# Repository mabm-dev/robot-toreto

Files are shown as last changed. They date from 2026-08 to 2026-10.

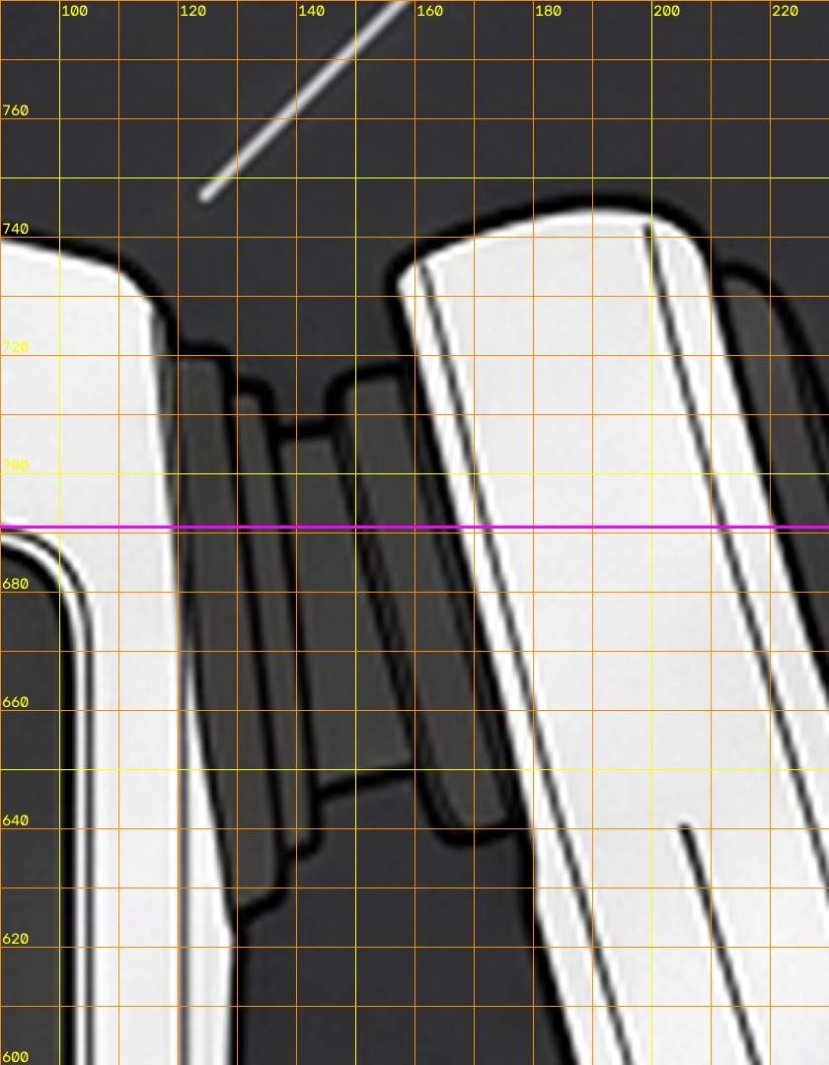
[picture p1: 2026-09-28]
work/Toreto_Prueba_Holguras_01_44/medicion_brazo/hombro_frontal.jpg

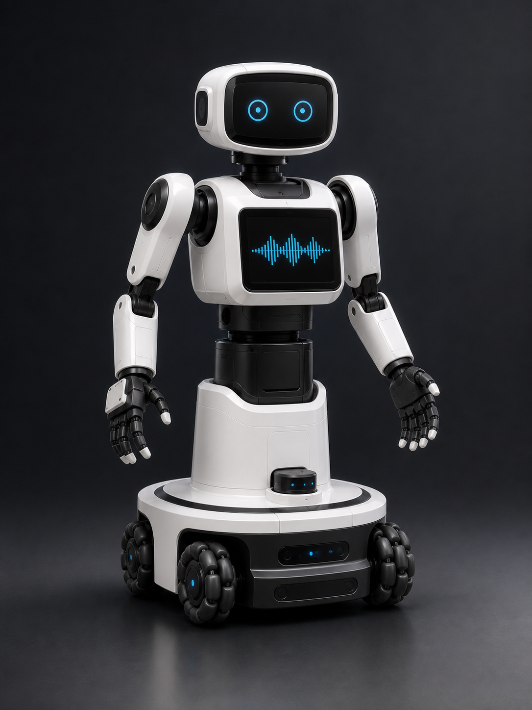
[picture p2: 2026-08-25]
cad-toreto/toreto_fusion_95cm/reference/concepto_fusion_95cm.png

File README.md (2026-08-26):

# Robot Toreto

Robot asistente de 95 cm impreso en 3D: base holonómica de 4 ruedas mecanum
con LIDAR, brazo de 6 grados de libertad por lado, cabeza de 2 grados de
libertad con cámara RGB-D, torso con pantalla táctil. Peso objetivo ~15 kg.

## Estado del proyecto

El proyecto avanza en tres fases fijas, en este orden — ver el porqué en
[`docs/DECISIONES.md`](docs/DECISIONES.md):

| Fase | Qué decide | Estado |
| --- | --- | --- |
| 1. Diseño | Forma, proporciones y módulos | 🟡 en curso — forma aprobada, proporciones finales pendientes |
| 2. Componentes | Batería, servos, motores, LIDAR, cámara, procesador | ⬜ no empezada — bloquea el resto |
| 3. CAD y materiales | Medidas definitivas y material pieza a pieza (Fusion) | 🟡 exterior avanzando — solo carcasas, sin mecánica ni cotas fijas (adelanto permitido, ver `DECISIONES.md`) |

Seguimiento del avance, en este repo:

- [`docs/ROADMAP.md`](docs/ROADMAP.md) — versiones y checklist de cada una
- [`docs/DECISIONES.md`](docs/DECISIONES.md) — por qué se tomó cada decisión
- [`docs/CINEMATICA.md`](docs/CINEMATICA.md) — árbol de links/joints previsto (planificación, no URDF final)

Documentos vivos (consulta desde cualquier dispositivo, se actualizan sobre la
misma URL):

- [Índice del proyecto](https://claude.ai/code/artifact/3c1e9e5f-cfa8-4d47-8dd7-55fb1f6f150b)
- [Lámina de diseño](https://claude.ai/code/artifact/774ba526-7714-4aee-aeff-1aad35ca3a55)
- [Stack de herramientas](https://claude.ai/code/artifact/6abfaa55-f3db-4c18-a0bd-476af38d9d59)

## Estructura del repositorio

```
cad-toreto/
├── visor-3d/                    # visor 3D interactivo (Three.js) — con este
│                                 # se aprobó la forma en v0.1
├── toreto_fusion_95cm/          # integración Autodesk Fusion 360 (fase 3, exterior)
│   ├── fusion_scripts/          #   10 add-ins de Fusion vigentes
│   ├── reference/lienzos_95cm/  #   4 vistas calibradas a 950mm + herramientas
│   │                             #   de medición (tools/measure_z_boundaries.py)
│   └── src/                     #   fuente paramétrica de la referencia volumétrica
├── toreto_exterior_95cm/        # piezas exteriores en OpenSCAD (fase 3, exterior)
│   ├── src/                     #   5 módulos .scad (base/tronco/pecho-hombros/
│   │                             #   cabeza-cuello/brazos)
│   ├── exports/                 #   STL por pieza
│   └── docs/                    #   una nota por módulo
├── toreto_v2.scad, toreto_reference_v1.scad, toreto_concept_v0.scad
│                                 # maquetas OpenSCAD anteriores (fase 1) — superadas
│                                 # por el trabajo de 95cm de arriba, se conservan
│                                 # como historial
└── exports/, exports_v1/, exports_v2/   # STL y renders de esas maquetas anteriores

docs/
├── ROADMAP.md               # versiones y checklist de cada una
├── DECISIONES.md            # por qué se tomó cada decisión importante
└── CINEMATICA.md            # árbol de links/joints previsto (planificación)
```

`toreto_fusion_95cm` y `toreto_exterior_95cm` describen el **mismo** exterior
de 95cm desde dos herramientas distintas (Fusion 360 y OpenSCAD) — hoy no
reparten los 950mm verticales de la misma forma entre sí; ver
`docs/DECISIONES.md` para el porqué no se ha fijado todavía una tabla única.

Hay también un cuaderno de aprendizaje (`docs/CUADERNO.md` en local) que es
deliberadamente privado y no está en este repositorio.

## Piezas y materiales

El trabajo exterior vigente (solo carcasas, sin mecánica) vive en
[`cad-toreto/toreto_fusion_95cm/`](cad-toreto/toreto_fusion_95cm/README.md)
(Fusion 360) y [`cad-toreto/toreto_exterior_95cm/`](cad-toreto/toreto_exterior_95cm/)
(OpenSCAD) — ver sus propios README. Ninguna pieza lleva todavía mecanismo
interno funcional (servos, reductoras, rodamientos reales): eso llega en la
fase 3 con los componentes ya elegidos, y las particiones verticales entre
módulos siguen sin fijarse por el mismo motivo (ver `docs/DECISIONES.md`).

`toreto_v2.scad` (y `lista_piezas_v2.md`, `guia_impresion_p1s.md`) es la
maqueta visual anterior — validó forma, proporción y que cada pieza entra en
el volumen de impresión de la Bambu Lab P1S (256 × 256 × 256 mm), pero está
superada por el trabajo de 95cm de arriba. Se conserva como historial, no
como referencia vigente.

Impresión: más perímetros antes que más relleno — 4-5 paredes con giroide al
25-30 %. Detalle en [`cad-toreto/guia_impresion_p1s.md`](cad-toreto/guia_impresion_p1s.md)
(de la maqueta anterior; sigue aplicando como criterio general de slicing).

## Herramientas

Fusion 360 (CAD final, fase 3), Bambu Studio (slicing), OpenSCAD (maquetas de
fase 1), KiCad / AutoCAD Electrical (electrónica), ROS 2 + Gazebo (control y
simulación, fase 3), NotebookLM (documentación).

## Licencia

Sin licencia definida todavía — todos los derechos reservados por defecto.

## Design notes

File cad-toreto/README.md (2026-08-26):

# cad-toreto — índice

Todo el CAD de Robot Toreto vive aquí, no en la raíz del repo (ver
`docs/DECISIONES.md` en la raíz para el porqué de cada decisión). Esta
carpeta acumula varias generaciones de trabajo — de más reciente/vigente a
más antigua/histórica:

## Vigente (fase 3, exterior — sin mecánica ni cotas fijas)

- **[`toreto_fusion_95cm/`](toreto_fusion_95cm/README.md)** — integración
  Autodesk Fusion 360: 10 add-ins, las 4 vistas de referencia calibradas a
  950mm (`reference/lienzos_95cm/`) y las herramientas que las generan y
  miden (`tools/`).
- **[`toreto_exterior_95cm/`](toreto_exterior_95cm/README.md)** — las mismas
  piezas exteriores en OpenSCAD: 5 módulos fuente, STL exportados y un
  render/doc por módulo.

Ambas carpetas describen el **mismo** exterior de 95cm desde herramientas
distintas y hoy no reparten los 950mm verticales de la misma forma entre sí
— la tabla única de cotas está deliberadamente sin fijar porque depende de
dónde queden batería y mecanismos internos (fase 2, todavía sin cerrar).

## Vigente (fase 1 — visor de forma)

- **[`visor-3d/`](visor-3d/README.md)** — visor 3D interactivo en Three.js;
  con él se aprobó la forma del robot (milestone v0.1 del roadmap).

## Histórico (maquetas anteriores, superadas)

- `toreto_v2.scad` (+ `lista_piezas_v2.md`, `README_V2.md`,
  `STL_EXPORTADOS_V2.md`, `exports_v2/`) — última maqueta OpenSCAD de fase 1
  antes de migrar a Fusion. Validó forma, proporción y que cada pieza cabe
  en el volumen de la Bambu P1S (256×256×256mm); no lleva mecanismo interno.
- `toreto_reference_v1.scad` (+ `README_V1_REFERENCIA.md`,
  `STL_EXPORTADOS_V1.md`, `exports_v1/`) y `toreto_concept_v0.scad`
  (+ `lista_piezas_concepto.md`) — generaciones anteriores a v2.
- `guia_impresion_p1s.md` — perfiles de slicing; el criterio general (más
  perímetros que relleno) sigue aplicando aunque las piezas cambien.
- `MIGRACION_95CM.md` — nota de la consolidación del 25 ago 2026 que separó
  lo que sí pasaba a 95cm de lo que se descartaba (rama de 65cm con servos
  ST-3215 ya elegidos — ver `toreto-gpt-descartado` en la memoria del
  proyecto, no forma parte de este repo).

No confundir con la carpeta hermana `cad-toreto-gpt/` (fuera de este repo,
en `.gitignore`) — es una rama paralela de 65cm descartada, no el proyecto
activo.

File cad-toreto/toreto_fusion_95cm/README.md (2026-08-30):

# Robot Toreto Fusion 95 cm

Integración de Autodesk Fusion 360 y referencias dimensionales del diseño
exterior vigente. Esta carpeta no contiene la antigua rama funcional de 65 cm.

## Alcance

- Altura exterior exacta: **950 mm**.
- Base compacta: **Ø400 × 225 mm**.
- Cuatro ruedas mecanum mostradas únicamente como volumen visual.
- Tronco, cintura, pecho, cuello y cabeza en módulos desmontables.
- Pantalla frontal horizontal.
- Brazos de **170 mm + 150 mm**.
- Mano antropomórfica: cuatro dedos de tres falanges y pulgar de dos falanges.
- Solo carcasas y piezas exteriores.

No incluye motores, esqueleto, rodamientos, ejes, cableado, electrónica ni
anclajes definitivos. Los alojamientos funcionales se diseñarán después de
seleccionar y medir los componentes reales.

## Distribución vertical de referencia

La tabla actualmente adoptada es la medida sobre la lámina maestra calibrada.
Las cotas internas y tolerancias siguen pendientes de los componentes reales.

| Módulo | Altura | Cota superior |
|---|---:|---:|
| Base | 200 mm | 200 mm |
| Tronco blanco | 190 mm | 390 mm |
| Cintura negra | 150 mm | 540 mm |
| Pecho | 190 mm | 730 mm |
| Cuello | 60 mm | 790 mm |
| Cabeza | 160 mm | 950 mm |

## Archivos conservados

- `fusion_scripts/`: versiones vigentes de los complementos de Fusion 360.
- `reference/lienzos_95cm/`: frontal, posterior y dos laterales calibrados
  entre `Z=0` y `Z=950 mm`.
- `reference/toreto_fusion_95cm_assembly.stl`: referencia volumétrica, no pieza
  fabricable.
- `reference/`: imágenes conceptuales aprobadas.
- `src/`: fuente paramétrica usada para regenerar la referencia volumétrica.
- `tools/prepare_fusion_canvases.py`: preparación reproducible de los lienzos.

Las piezas exteriores exportables vigentes están en la carpeta hermana
`toreto_exterior_95cm`; se retiraron de aquí los STL preliminares duplicados.

## Estado

Es una maqueta CAD exterior y paramétrica para cerrar apariencia, partición y
volúmenes. Los complementos construyen geometría de revisión, no mecánica
definitiva. Antes de imprimir el conjunto completo hay que:

1. confirmar motores, ruedas, servos, sensores y batería;
2. introducir sus envolventes reales en Fusion 360;
3. definir tornillería, insertos, tolerancias y nervios;
4. comprobar alcance y par de brazos;
5. laminar prototipos parciales en Bambu Studio u OrcaSlicer.

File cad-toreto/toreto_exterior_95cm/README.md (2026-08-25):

# Robot Toreto — piezas exteriores de 95 cm

Diseño por módulos basado directamente en la referencia visual aportada. El
trabajo se organiza en este orden:

1. Base.
2. Tronco.
3. Hombros y pecho.
4. Cabeza y cuello.
5. Brazos y manos.

El alcance incluye únicamente carcasas, paneles y acabados visibles. No incluye
ruedas, motores, servos, ejes, rodamientos, chasis, esqueleto ni anclajes.

## Módulos conservados

- `src/`: fuentes paramétricas OpenSCAD y exportadores de los cinco módulos.
- `docs/`: cotas, despiece y límites de cada módulo.
- `exports/`: STL exteriores separados por módulo.
- `renders/`: vistas de comprobación estética.

Los STL de esta carpeta son piezas exteriores de referencia. Antes de fabricar
hay que revisar espesores, tolerancias, uniones y compatibilidad con el hardware
real que se seleccione.

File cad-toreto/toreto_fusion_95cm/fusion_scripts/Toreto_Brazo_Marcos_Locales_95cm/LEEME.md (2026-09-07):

# Brazo Toreto — prueba de marcos locales 1.0.35

La 1.0.35 conserva exactamente la implantacion y el giro hacia dentro del
pulgar de la 1.0.34. Invierte el sentido de flexion de los cuatro dedos
principales para que cierren desde la cara opuesta de la palma.

Las dieciseis juntas principales usan ahora los intervalos -60..0, -60..0,
-50..0 y -40..0 grados. Los topes fisicos se trasladan al mismo lado angular,
incluida la compensacion por contacto de los nervios. Las relaciones mantienen
las magnitudes progresivas 60/60/50/40. El pulgar conserva sus intervalos
0..30, 0..40, 0..35 y 0..20 grados, sus ejes, su posicion y su geometria.

Para validar en Fusion, anima las relaciones de `JUNTA_DEDO_1_1` y despues
`JUNTA_PULGAR_1`: deben cerrar hacia caras opuestas y encontrarse sobre la
palma sin cambiar la posicion abierta.

La 1.0.34 conserva la forma de giro validada visualmente en la 1.0.33, pero
refleja toda la implantacion del pulgar al lado opuesto del cierre de los dedos
principales. El anclaje, el cardan, las tres falanges y sus cuatro ejes se
transforman como un único mecanismo respecto al plano medio Y=48,4595 mm.

El pulgar abierto queda en la cara Y positiva, con la raiz en Y=68,0641 mm y
el anclaje en la misma cara exterior, Y=58,4595 mm. Al cerrar, las falanges
proximales permanecen fuera de la cubierta y la yema gira hacia dentro hasta
Y=47,32 mm. La horquilla abierta de 10 mm evita que el cardan nazca dentro de
la base maciza.

Se conservan los recorridos 30/40/35/20, la separacion de 76 grados entre los
ejes de base, las 20 juntas, las 15 relaciones y todas las fijaciones.

La 1.0.33 corrige el signo de profundidad de la 1.0.32. Los dedos principales
cierran hacia la cara Y positiva, por lo que el pulgar debe partir en la cara
opuesta. La cadena se desplaza 16 mm hacia Y negativa y los dos ejes del cardan
se recalculan con una separacion aproximada de 76 grados.

La abertura del soporte aumenta de 7,2 a 10 mm y atraviesa el extremo de la
base reforzada, formando una horquilla real alrededor del cardan. Durante el
cierre calculado, los tres puntos proximales se mantienen fuera de la palma en
Y=28,9, 25,7 y 28,2 mm. Despues la cadena cruza bajo el borde: la siguiente
articulacion alcanza Y=38,9 mm y la yema Y=49,6 mm para oponerse a los dedos.

Se conservan los recorridos 30/40/35/20, las 20 juntas, las 15 relaciones y
las fijaciones completas del brazo, de la mano y de la palma.

La 1.0.32 corrige la penetracion fisica visible en las vistas lateral y oblicua
de la 1.0.31. La base reforzada terminaba en un volumen macizo alrededor del
primer pivote, por lo que el cardan y la primera falange atravesaban la propia
palma al cerrar.

Ahora la base incorpora una cuna abierta de 7,2 mm de radio entre los dos ejes
del cardan. La cadena completa del pulgar se adelanta 14 mm hacia la cara
palmar y sus ejes cruzados se recalculan con una separacion aproximada de 88
grados. En la postura cerrada calculada, los tres puntos proximales quedan a
58,9, 61,9 y 63,9 mm de profundidad, delante de la cubierta, mientras la yema
regresa a 54,4 mm para oponerse a los dedos.

Se conservan los recorridos 30/40/35/20, las 20 juntas, las 15 relaciones y
las fijaciones completas del brazo, de la mano y de la palma.

La 1.0.31 afina la trayectoria observada en las dos animaciones de la 1.0.30.
Reduce el barrido lateral de la primera junta del pulgar de 40 a 30 grados,
aumenta la oposicion de la segunda de 30 a 40 grados, mantiene 35 grados en la
tercera y reduce la terminal de 25 a 20 grados. El objetivo es eliminar la
forma de Z, redondear el cierre y orientar mejor la yema hacia los dedos.

Se conserva sin cambios el cardan de ejes cruzados, los 21 componentes, las 20
juntas, las 15 relaciones de movimiento, los cuatro dedos principales y todas
las fijaciones del brazo y de la mano.

La 1.0.30 incorpora un pequeño cardan entre la palma y la primera falange del
pulgar. Sus dos ejes de base se cruzan aproximadamente 78 grados: el primero
produce un barrido lateral de 40 grados y el segundo añade 30 grados de
oposicion hacia los tres dedos derechos. Las dos bisagras distales, paralelas
al eje de oposicion, aportan 35 y 25 grados para completar el cierre natural.

La cadena del pulgar pasa a tener cuatro juntas y tres relaciones de cierre.
La mano contiene 21 componentes, 20 juntas revolutas y 15 relaciones de
movimiento. Se mantienen los limites 60/60/50/40 de los cuatro dedos
principales y la fijacion del brazo, del conjunto de mano y de la palma.

La 1.0.29 sustituye el barrido plano del pulgar de la 1.0.28 por una flexion
oblicua. El eje se calcula a partir del rayo abierto del pulgar y del centro de
las raices de los tres dedos situados a su derecha. Las tres bisagras quedan
paralelas en ese plano y usan 50/25/15 grados; esta combinacion lleva la punta
hacia dicho centro con una curva continua y evita plegarla sobre si misma.

Tambien fija a la raiz el componente superior completo. La mano y la palma ya
estaban fijadas internamente, pero Fusion podia escoger el brazo como lado
movil al animar relaciones desde `JUNTA_DEDO_n_2`, `_3` o `_4`. Esta fijacion
mantiene inmovil todo el brazo independientemente de la junta conducida.

La 1.0.28 corrige la trayectoria del pulgar observada en la animacion de la
1.0.27. Su primera bisagra deja de usar el mismo eje transversal que las otras
dos: ahora gira alrededor de la normal negativa de la palma. En la postura
frontal aprobada, este eje desplaza el pulgar hacia los tres dedos situados a
su derecha y crea el movimiento de oposicion.

Las juntas segunda y tercera mantienen sus ejes transversales para curvar la
punta durante la oposicion. Se conservan los recorridos 60/55/45 grados, las
dos relaciones de movimiento del pulgar y todos los valores de los cuatro
dedos principales.

La 1.0.27 aumenta el cierre de los dedos principales con un reparto progresivo
de 60/60/50/40 grados. Las dos primeras juntas acercan toda la cadena a la
palma; las dos ultimas orientan la punta sin plegarla en exceso sobre si misma.

El pulgar queda adaptado a 60/55/45 grados y recibe dos relaciones de
movimiento. En total se crean catorce relaciones: doce para los cuatro dedos
principales y dos para el pulgar. Los valores de cada relacion reproducen la
proporcion de los limites y los topes fisicos correspondientes.

La 1.0.26 limita a 45 grados cada una de las cuatro juntas de los dedos
principales. Los topes fisicos se regeneran con el mismo recorrido. El cierre
acumulado puede alcanzar 180 grados, pero se reparte entre las cuatro falanges
en vez de concentrar 90 grados o mas en cada nudillo.

Tambien crea doce relaciones de movimiento: la primera junta de cada dedo
controla las otras tres con relacion 1:1. Para comprobar el cierre conjunto en
Fusion debe usarse `Animar relaciones de unión` sobre `JUNTA_DEDO_n_1`.
`Editar límites de movimiento` sigue previsualizando una junta aislada.

La 1.0.25 corrige el sentido estructural observado al animar
`JUNTA_DEDO_1_1` en la 1.0.24. Fusion mueve el primer componente indicado al
crear una junta respecto al segundo. La versión anterior entregaba primero la
palma o la falange proximal, de modo que la animación desplazaba la mano
completa alrededor del dedo seleccionado.

Ahora cada junta entrega primero la falange distal y después la palma o
falange proximal. También fija temporalmente `06_MANO_ARTICULABLE` a su
componente padre, además de mantener fijada la palma dentro del subconjunto.
Al animar una junta debe permanecer inmóvil el brazo y girar únicamente la
falange seleccionada. `Animar relaciones de unión` permitirá comprobar después
el movimiento de toda la cadena distal.

La 1.0.24 utiliza la jerarquía validada en la 1.0.23 para crear 19 juntas
revolutas reales: cuatro por cada dedo principal y tres para el pulgar. La
palma queda fijada al componente `06_MANO_ARTICULABLE`; cada falange mantiene
un único grado de libertad alrededor del pasador transversal correspondiente.

El eje de cada junta se obtiene directamente de un borde circular del pasador.
El script verifica que su radio sea 2 mm y que su normal coincida con el eje
transversal calculado. Si la orientación del borde está invertida, invierte
también el intervalo angular para conservar el cierre hacia la palma.

Las juntas principales usan límites 0–90°, 0–100°, 0–85° y 0–65°. Las juntas
del pulgar usan 0–70°, 0–90° y 0–75°. Fusion puede conducir cada junta dentro
de esos intervalos sin recolocar la postura abierta durante su creación.

La 1.0.23 conserva exactamente la geometría y los topes validados en la
1.0.22, pero reorganiza la mano como un conjunto mecánico. Bajo el componente
`06_MANO_ARTICULABLE` crea 20 componentes hijos: la palma, las 16 falanges de
los cuatro dedos principales y las tres falanges del pulgar.

En cada articulación, los dos casquillos exteriores y el pasador desmontable
pertenecen al componente proximal. El casquillo central pertenece al componente
distal junto con su falange. Esta distribución hace que cada pareja comparta
el mismo eje físico y deja preparada la jerarquía necesaria para crear juntas
revolutas con límites angulares en la siguiente etapa.

Los sólidos conservan sus coordenadas globales y las ocurrencias nuevas usan
transformación identidad. Por ello la postura, la alineación con la muñeca y
la silueta no deben cambiar respecto a la 1.0.22. El recuento sigue siendo de
96 cuerpos para la mano y 101 para el conjunto completo.

La 1.0.22 conserva la mano, la palma y los 96 cuerpos validados en la 1.0.21.
Cada nudillo incorpora ahora un tope móvil unido al casquillo central y dos
topes fijos unidos a los casquillos exteriores. Son nervios cilíndricos de
1,25 mm de radio que se integran mediante unión booleana, de modo que no crean
piezas sueltas ni interfieren con el taladro o con la extracción del pasador.

Los recorridos nominales de los cuatro nudillos de cada dedo son 90°, 100°,
85° y 65° desde la palma hacia la punta. Los tres recorridos del pulgar son
70°, 90° y 75°. La posición angular incluye el radio de contacto de ambos
topes para que el contacto ocurra al alcanzar el límite y no antes.

Esta versión comprueba en Fusion la creación de las uniones booleanas y que
los topes permanezcan fuera del taladro. Los canales de accionamiento y la
conversión de falanges a componentes móviles quedan para la etapa siguiente.

La 1.0.21 conserva la geometría exterior aprobada en la 1.0.20 y sustituye los
19 cilindros visuales de los dedos por articulaciones mecánicas. Cada nudillo
contiene dos casquillos exteriores, un casquillo central y un pasador coaxial
independiente.

El pasador tiene 4 mm de diámetro y sobresale 1 mm por cada lado. Los casquillos
usan un taladro de 4,70 mm, equivalente a 0,35 mm de holgura radial, y dejan
0,40 mm de separación axial a cada lado del casquillo central. Los cuatro
cuerpos permiten comprobar visualmente el montaje y mantienen accesible el
pasador para desmontaje.

Esta etapa valida primero los casquillos, taladros y pasadores en Fusion. Los
límites nominales previstos son 90° / 100° / 85° / 65°. Los topes físicos y los
canales de accionamiento se incorporarán después de confirmar que los 19
conjuntos se generan sin errores y mantienen la silueta aprobada.

La 1.0.20 elimina la forma de campana visible en la vista inferior. La
profundidad de la palma negra baja de 44 a 20 mm en el nacimiento de los dedos,
frente a falanges de 14–15 mm. Aumenta gradualmente a 21, 22, 24 y 26 mm al
acercarse al conector de muñeca, cuyo diámetro de 26 mm queda completamente
recibido.

El desplazamiento del centro en profundidad se reduce de 8 a 2,5 mm para que
la palma se lea como una placa humanoide. Los cuatro dedos se trasladan 5,5 mm
con la nueva superficie de nudillos; sus longitudes, alineación, ejes, arco
cubital, cunas separadas y terminales abombadas permanecen intactos.

La 1.0.19 conserva exactamente la alineación de palma, nudillos y dedos de la
1.0.18. Sustituye las esferas terminales por falanges blancas de cuatro
secciones: mantienen su anchura durante el 68 % de la longitud y se reducen
progresivamente hasta un extremo abombado. La terminal recibe ahora el 27 % de
la longitud total de cada dedo.

Las cunas de los nudillos reducen su radio a 7 mm y penetran 6 mm en la palma.
Así permanecen separadas por material visible en vez de formar un borde recto
continuo. El arco transversal se reparte en 1,5 / 0 / 2,5 / 5 mm desde el índice
hasta el meñique, aumentando la capacidad de ahuecar la palma hacia el lado
cubital. El pulgar utiliza la misma terminal abombada sin esfera.

La 1.0.18 usa el conector negro de muñeca como eje maestro de toda la mano.
La palma rota 13,40 grados respecto a la postura heredada, sus centros locales
se alinean sobre una recta y la fila de nudillos se construye perpendicular a
ese eje. Los cuatro dedos salen paralelos al conector, sin abanico ni torsión.

La palma mide ahora 60 mm de longitud y conserva 76 × 44 mm en los nudillos.
Cuatro cunas redondeadas se integran en su borde para recibir las articulaciones
proximales. Los dos dedos centrales avanzan 2 mm en profundidad para crear un
arco palmar suave. Las falanges terminales blancas son más largas y anchas.

El pulgar rota junto con la palma, aumenta hasta 18 × 16 mm en su base y su
tercera falange se convierte en una terminal blanca alargada y redondeada.

La 1.0.17 gira los ejes de los nudillos 90 grados respecto a la prueba anterior.
Cada eje se calcula como el transversal del rayo local de su dedo: atraviesa el
ancho de la falange y permite que el movimiento ocurra en profundidad, hacia la
palma. En frontal debe leerse como una banda y en lateral como un círculo.

La palma crece moderadamente hasta 76 × 44 mm en el borde de nudillos. Las
raíces se separan 16,5 mm, las carcasas aumentan aproximadamente un 10 %, las
longitudes crecen un 3 % y la falange blanca terminal recibe más longitud y
volumen. El pulgar conserva la oposición neutra y usa su propio eje transversal
oblicuo, calculado desde su dirección.

La 1.0.16 convierte el esqueleto cinemático de la 1.0.15 en una mano modular
más próxima a las referencias. Las falanges principales aumentan hasta
14 × 13 mm en la base y 13 × 12,5 mm en la punta. Entre ellas aparecen nudillos
cilíndricos transversales independientes, incluido el nudillo de la palma.

Los cuatro dedos conservan sus longitudes diferentes, separan sus raíces a
15 mm y forman un abanico neutro total de 6 grados. La cuarta falange es blanca,
alargada y redondeada. El borde de la palma crece hasta 68 × 40 mm para rodear
las bases. El pulgar queda recto en oposición neutra y recibe tres nudillos
independientes. Las futuras posturas curvas se obtendrán girando estos cuerpos.

La 1.0.15 corrige la cinemática visual de los cuatro dedos principales usando
las nuevas referencias `manos robot.png` y `Copy_arm_design_from_image_202608242013.jpeg`.
Cada dedo nace en la posición ya aprobada y queda recto en reposo. Su eje tiene
una ligera convergencia hacia el centro de agarre, pero ninguna falange contiene
una curvatura permanente.

Cada dedo se divide ahora en cuatro cuerpos articulables: tres falanges negras
y una falange terminal blanca con punta redondeada. La longitud total de cada
dedo se conserva y se reparte en proporciones 29/27/24/20. La futura postura de
agarre se obtendrá girando las uniones transversales entre cuerpos.

La 1.0.13 colocó la rótula en el centro del perfil terminal, pero ese perfil
incluye la antigua protuberancia lateral de la horquilla. Por eso la muñeca
apareció desplazada aunque su salida siguiera la dirección del antebrazo.

La 1.0.14 conserva la altura longitudinal del extremo y toma el centro
transversal del primer perfil estable del núcleo. La corrección es de
0,08 mm en X, -23,49 mm en Y y 0,02 mm en Z. La envolvente, la rótula, el
conector y la mano completa se trasladan juntos, de modo que el esfuerzo entra
por el centro resistente del antebrazo y todas las uniones permanecen alineadas.

Las capturas de la 1.0.12 validaron la nueva mano y el pulgar reforzado. También
mostraron que la protección blanca de muñeca seguía abierta como una horquilla,
dejando demasiado vástago negro visible y concentrando el esfuerzo en la salida.

La 1.0.13 sustituye ese alojamiento por una envolvente esférica blanca R31,80 mm
unida al antebrazo. En su interior deja una cavidad para la rótula negra R13,36
mm y abre un único conducto inferior alineado con el eje del antebrazo. El
conector negro aumenta de R11 a R13 mm y nace exactamente en el centro de la
rótula. La protección queda cerrada delante, detrás y en ambos laterales; solo
queda abierta la salida necesaria hacia la palma.

Las vistas frontal y lateral derecha de la 1.0.11 confirmaron la nueva palma,
pero mostraron que el pulgar seguía comportándose como una pinza en voladizo:
su raíz estaba demasiado alejada en profundidad y dependía de un enlace fino.

La 1.0.12 adopta la arquitectura de `concepto_mano_5_dedos.png` y del módulo
`arms_exterior_95cm.scad` del repositorio. El pulgar nace de una base lateral
R12 mm integrada en la palma, permanece cerca de su plano de trabajo y utiliza
tres falanges robustas de 16 × 14, 14 × 12 y 12 × 10 mm. Los centros de sus
tramos quedan separados aproximadamente 28,6, 20,0 y 15,3 mm. Los cuatro dedos
principales, la palma 1.0.11 y todas las articulaciones del brazo se conservan.

Fusion creó correctamente la 1.0.10 y confirmó las nuevas falanges rectangulares
redondeadas. La revisión visual mostró que la palma negra era demasiado corta
y profunda, con una apertura que recordaba a una campana. La 1.0.11 conserva
la articulación de muñeca, el metacarpiano del pulgar y las cinco trayectorias,
pero rehace la silueta de la palma con cinco perfiles.

La palma mide 51 mm entre el frente de nudillos y la muñeca. Su ancho disminuye
de 60 a 38 mm y su profundidad de 36 a 26 mm. Así queda más larga, delgada y
claramente separada de la articulación circular de la muñeca.

Las capturas de la 1.0.9 validaron la unión del pulgar, la posición de la mano
y las proporciones de sus cinco trayectorias. La 1.0.10 conserva exactamente
los puntos medidos y el recorte de 0,6 mm en cada extremo de falange. Sustituye
solo los cilindros provisionales por carcasas macizas de sección rectangular
redondeada, con una reducción del 6 % hacia la punta. Cada dedo decrece de
11 × 10 a 9 × 8 mm; el pulgar decrece de 14 × 12 a 12 × 10 mm.

Esta versión sigue usando cuerpos independientes para cada falange. La prueba
comprueba el acabado exterior; los pasadores, las holguras de giro y el espesor
de pared se definirán después de aprobar la silueta.

La 1.0.8 corrigió el volumen de la palma y la posición de los cuatro dedos.
Las capturas mostraron que la primera falange del pulgar quedaba separada en
el espacio. La 1.0.9 añade un metacarpiano negro R8 mm desde el centro interior
del extremo proximal de la palma hasta la raíz medida del pulgar. Se une a la
palma, solapa con la primera falange y conserva la trayectoria del pulgar.

La 1.0.7 confirmó la colocación de la mano, pero la palma quedó sobredimensionada
porque la envolvente incluía también la rama del pulgar. La 1.0.8 rastrea el
intervalo principal de la palma por separado: el ancho pasa de 53,80 a 56,74
mm y la profundidad central se reduce progresivamente de 80 a 62 mm. Los
cuatro dedos se desplazan sobre ese intervalo principal para que sus bases
queden dentro de la palma. El pulgar conserva su trayectoria independiente.

Las vistas de Fusion validaron el hombro y la muñeca de la 1.0.6. La 1.0.7
añade una primera reconstrucción completa de la mano. La palma utiliza cuatro
secciones locales estables del contorno medido; un enlace negro R11 mm la une
al eje de muñeca. Los cuatro dedos tienen tres falanges independientes y el
pulgar dos. Las trayectorias X/Z proceden de las guías frontales y la posición
Y de las guías laterales transformadas al marco propio de la mano. Las puntas
son cuerpos blancos separados.

Esta etapa valida postura y proporciones exteriores. Las falanges aún son
cilíndricas y no incluyen pasadores ni límites de giro; se mantienen separadas
para reemplazarlas por carcasas detalladas después de validar el conjunto.

Las vistas frontal y lateral validaron el codo de la 1.0.5. La 1.0.6 conserva
sin cambios esa geometría y utiliza los dos perfiles terminales que no podían
interpolarse como articulaciones independientes. El extremo del brazo define
un alojamiento lateral de hombro de 110,63 mm de diámetro y 17,86 mm de
longitud. El extremo del antebrazo define una brida de muñeca de 63,60 mm de
diámetro y 10,32 mm de longitud. Ambos reciben ejes negros separados con 0,8
mm de holgura radial.

El loft del brazo termina ahora antes del perfil de hombro y el del antebrazo
antes del perfil de muñeca. Así se elimina la extensión provisional de perfil
constante y cada cambio abrupto corresponde a una pieza real del conjunto.

La vista lateral de la 1.0.4 validó el aro y el eje. La frontal mostró que un
cilindro blanco continuo cerraba el hueco central. La 1.0.5 divide el
alojamiento en dos mejillas laterales de 8,89 mm y deja entre ellas la abertura
de 47,57 mm medida en el contorno frontal. El eje y el enlace negros quedan
visibles en el centro, mientras la vista lateral conserva el aro blanco.

La comparación de la 1.0.3 con el lateral de referencia mostró que el eje era
correcto, pero todavía faltaban dos volúmenes visibles: el alojamiento circular
blanco solidario al antebrazo y el enlace negro entre el extremo del brazo y
el pivote. La 1.0.4 los añade alrededor del mismo centro ya validado.

El alojamiento exterior usa R27,78 mm y el taladro mantiene 0,8 mm de holgura
respecto al eje. El brazo se recorta alrededor del alojamiento completo para
evitar solapes. El eje y su enlace forman un cuerpo negro independiente del
antebrazo, conservando la separación necesaria para una articulación futura.

Las capturas de la 1.0.2 confirman que el eje se ve como puente rectangular
en frontal y como círculo en lateral. La 1.0.3 corta en las dos carcasas sendos
alojamientos coaxiales con el mismo eje y 0,8 mm de holgura radial. El cortador
penetra 2,3 mm desde cada plano terminal para eliminar el contacto plano sin
debilitar el núcleo. El eje continúa siendo un cuerpo independiente.

Las capturas de Fusion de la 1.0.1 validaron los dos núcleos: superficies
continuas, silueta frontal estable y profundidad sin pliegues. La 1.0.2
prolonga el perfil estable más próximo hasta cada plano terminal medido. De
esta forma completa la longitud sin interpolar los radios extremos que
autointersectaban el loft. Los collares solapan 0,5 mm con el núcleo antes de
unirse.

El hueco entre los planos opuestos del brazo y antebrazo determina ahora un
eje transversal de codo independiente. Su centro y radio proceden de esos dos
planos, y su dirección es la normal frontal media de los enlaces. Sigue siendo
una validación volumétrica: aún no define tolerancias, rodamientos ni espesor.

Fusion rechazó el loft completo 1.0.0 por autointersección. El diagnóstico
numérico localizó el pliegue en los cambios extremos: el último salto del brazo
y el primero y los dos últimos del antebrazo cambian de centro/radio más rápido
que su separación longitudinal. La 1.0.1 selecciona automáticamente el tramo
continuo más largo con razón de cambio local máxima 1.5. Conserva las 17
secciones medidas en el JSON; únicamente aplaza los perfiles terminales para
que esta ejecución valide primero los dos volúmenes principales.

Las vistas frontal y lateral muestran posturas distintas. Sus guías confirman
que no representan el mismo eje global: brazo 161.20/120.81 mm y antebrazo
90.25/131.53 mm en frontal/lateral. Cruzarlas mediante planos horizontales Z,
como en las pruebas 1.0.2–1.0.10, mezcla regiones longitudinales distintas.

Esta prueba no reinicia los trazados. Convierte cada contorno existente a un
marco propio definido por `upper_shell_axis` o `forearm_shell_axis`. En cada
vista mide la envolvente perpendicular a ese eje y empareja ancho/profundidad
por posición longitudinal normalizada. Luego orienta el sólido con el eje
frontal, que sigue siendo la postura maestra. El lateral aporta profundidad,
sin imponer su postura global.

Se usa Y=45 mm como plano neutro compartido para colocar ambos enlaces en la
postura frontal. Es una colocación visual de prueba, no una cota mecánica. La
geometría conserva desplazamientos locales respecto a las guías, por lo que
las secciones no quedan forzadas a centros simétricos.

Los extremos se limitan a un intervalo continuo con ancho y profundidad de al
menos 10 mm. Hay 17 secciones por pieza, más densas cerca de los extremos.
Cuando un rebaje crea varios intervalos se usa la envolvente exterior; por eso
esta primera prueba local no contiene aberturas. Tampoco incluye articulaciones,
mano, espesor o mecanismo.

Ejecutar `Toreto_Brazo_Marcos_Locales_95cm`. Crea
`94_BRAZO_MARCOS_LOCALES_PRUEBA_01` sin modificar las pruebas 90–92 ni los
lienzos. Ocultar manualmente los demás brazos para comparar superficies y la
silueta frontal. No se espera superposición con el lienzo lateral mientras el
modelo esté en la postura frontal.

La sintaxis y los cálculos numéricos se comprueban localmente. La ejecución del
loft y la calidad de sus superficies requieren Fusion. El usuario guarda el
documento de Fusion.

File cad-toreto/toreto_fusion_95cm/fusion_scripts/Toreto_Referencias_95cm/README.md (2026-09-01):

# Toreto_Referencias_95cm

Secuencia de Autodesk Fusion para colocar dentro de `00_REFERENCIAS` cuatro
lienzos ortogonales del robot:

- `PATRON_01_FRONTAL_95CM` y `PATRON_02_POSTERIOR_95CM`, en el plano XZ;
- `PATRON_03_LATERAL_IZQUIERDO_95CM` y
  `PATRON_04_LATERAL_DERECHO_95CM`, en el plano YZ;
- la malla STL completa, si existe, como comprobación adicional.

Todos los lienzos comparten escala y origen: contacto con el suelo en `Z=0`
y parte superior de la cabeza en `Z=950 mm`. Solo el frontal queda visible al
terminar. En `00_REFERENCIAS > Lienzos`, apaga su bombilla y enciende la vista
que necesites para evitar superposiciones.

Desde la versión 2.1.0, las cuatro siluetas se calibran de forma independiente
contra sus límites auditados y ocupan exactamente 1900 intervalos a
`0,5 mm/píxel`; los márgenes originales de la lámina no afectan a la escala.

La versión 2.5.0 consolida las correcciones comprobadas en Fusion:

- usa una matriz distinta para XZ y YZ, manteniendo Z vertical;
- ancla cada vista por el eje central de la base, no por el centro del PNG;
- lee los anclajes de eje desde `calibracion_95cm.json`, sin constantes
  duplicadas;
- aplica el espejo horizontal necesario en la vista lateral izquierda para
  que las dos laterales compartan la misma coordenada Y;
- elimina de `00_REFERENCIAS > Lienzos` cualquier lienzo antiguo y conserva
  exclusivamente los cuatro patrones calibrados de 95 cm.

Las referencias no son piezas fabricables. El script es repetible: actualiza
los lienzos existentes sin duplicarlos y no duplica la malla existente.

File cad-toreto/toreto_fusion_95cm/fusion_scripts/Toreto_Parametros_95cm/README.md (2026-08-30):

# Toreto_Parametros_95cm

Inicializa la única tabla vertical vigente del robot según la lámina maestra:

`200 + 190 + 150 + 190 + 60 + 160 = 950 mm`

Ejecutar primero en un documento de Fusion nuevo o antes de regenerar módulos.
Después ejecutar `Toreto_Componentes_95cm`, los generadores de piezas y, al
final, `Toreto_Alinear_Montaje_95cm`.

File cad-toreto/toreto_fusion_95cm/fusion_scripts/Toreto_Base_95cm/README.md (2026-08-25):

# Toreto_Base_95cm

Crea dentro de `01_BASE` una primera base CAD nativa a escala real:

- faldón y banda sensora;
- carcasas blancas superior e inferior;
- anillos y tapa superior;
- cuatro ruedas mecanum como piezas exteriores visuales;
- sensores frontales y torreta superior.

No crea motores, ejes, rodamientos, estructura ni electrónica. La revisión
1.2 usa ruedas radiales a 45 grados, paneles frontales redondeados, faldón
negro con cubiertas laterales blancas, torreta elevada y una tapa superior
continua. Al ejecutarla sobre la revisión anterior, sustituye solo
los cuerpos `BASE95_` creados por esta secuencia y no genera duplicados.

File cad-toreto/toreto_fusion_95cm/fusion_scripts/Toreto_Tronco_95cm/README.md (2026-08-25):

# Toreto_Tronco_95cm

Genera el módulo exterior `02_TRONCO` a partir de la altura maestra de 185 mm.
Incluye carcasa blanca cónica, núcleo negro visual, panel de sensores y tapa
de acceso. No crea estructura, batería, electrónica ni anclajes mecánicos.

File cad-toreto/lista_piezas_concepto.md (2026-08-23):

# Lista de piezas - Toreto V0

## Piezas imprimibles

| Pieza | Cantidad | Material | Comentario |
| --- | ---: | --- | --- |
| Base cuadrante | 4 | PETG | Forma el anillo exterior de 400 mm |
| Placa central base | 1 | PETG-CF | Union de base, columna y electronica |
| Caja electronica | 1 | PETG | Para reguladores, hubs y controladores |
| Tapa/sensor frontal | 1 | PETG | Huecos para sensores o camara frontal |
| Cubierta rueda | 3 | PETG | Estetica/proteccion, no rueda funcional |
| Torso frontal | 1 | PETG | Hueco de pantalla tactil |
| Torso trasero | 1 | PETG | Acceso a electronica y cableado |
| Montura hombro izquierda | 1 | PETG-CF | Debe reforzarse con eje metalico |
| Montura hombro derecha | 1 | PETG-CF | Debe reforzarse con eje metalico |
| Columna cuello | 1 | PETG-CF | Paso de cables interior |
| Cabeza frontal | 1 | PETG | Hueco de pantalla/cara y camaras |
| Cabeza trasera | 1 | PETG | Cierre de cabeza |
| Orejas/laterales cabeza | 2 | PETG | Soportes laterales |
| Brazo superior | 2 | PETG-CF | Carcasa, no estructura final unica |
| Antebrazo | 2 | PETG-CF | Carcasa, no estructura final unica |
| Muneca/pinza conceptual | 2 | PETG-CF | Concepto de pinza ligera |

## Componentes no imprimibles

| Componente | Cantidad orientativa | Nota |
| --- | ---: | --- |
| Motores con encoder para base | 3 | Mejor comprar con reductora |
| Ruedas omni/mecanum | 3 | No recomiendo imprimirlas como pieza funcional |
| Driver motores | 1-3 | Segun motor elegido |
| Bateria 24 V | 1 | Li-ion/LiFePO4 con BMS |
| Reguladores DC-DC | 2-3 | 24 V a 12 V, 5 V y/o 19 V |
| Raspberry Pi 5 / Jetson / mini PC | 1 | Control local y puente con agentes |
| ESP32 / Arduino / STM32 | 1-2 | Control en tiempo real de motores/servos |
| Camara | 1-2 | Cara/cabeza o vision frontal |
| Microfonos | 1 | Preferible array USB |
| Altavoz + amplificador | 1 | Voz de Toreto |
| Pantalla cabeza | 1 | Cara expresiva |
| Pantalla torso | 1 | Opcional |
| IMU | 1 | Estabilidad y orientacion |
| Sensor distancia / LiDAR | 1 | Navegacion y seguridad |
| Boton parada emergencia | 1 | Muy recomendado |
| Rodamientos/ejes/tornilleria | varios | M3, M4, M5 e insertos termicos |

## Fases

### Fase 1 - Maqueta

Imprimir cabeza, torso y base sin motores para revisar escala, acceso a tornillos, paso de cables y presencia fisica.

### Fase 2 - Base movil

Montar la base con motores, encoders, bateria, control local y parada de emergencia.

### Fase 3 - IA fisica

Anadir cabeza con pantalla, camara, microfonos y comunicacion con tu sistema de agentes.

### Fase 4 - Brazo

Empezar con una pinza ligera y pocos grados de libertad antes de pasar a 6 DOF.

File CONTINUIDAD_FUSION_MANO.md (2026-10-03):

# Continuidad del proyecto Toreto — actualizado el 3 de octubre de 2026

## 00. AL RETOMAR (3 oct 2026): EMPEZAR AQUÍ

### Qué está esperando al usuario (lunes 5 oct)

- **Desguace:** buscar motores de tornillo sin fin (lista abajo) y precios.
- **Su tío (aluminio):** le lleva `docs/fabricacion/lista_corte_aluminio_v0_2.pdf`
  (18 piezas, solo aluminio, sin precios, sin taladros) para ver qué puede
  conseguir, qué recortes tiene y a qué precio.
- Al volver: con los motores reales (modelo + fotos con regla) se diseñan
  soportes, acoples y el esqueleto en Fusion → **lista de corte v1 con
  taladros acotados** (y DXF si su tío tiene máquina de corte).

### Estado del robot (montaje `Toreto_hombro_encajado_sin_articulaciones_backup`)

Exterior completo, ~965 mm, comprobado (modo `comprobar`: juntas bien,
0 choques brazos-resto). Versiones vigentes de los complementos:

| Módulo | Versión | Notas |
|---|---|---|
| Base | 2.0.1 | Redonda Ø450, mecanum con aspecto del render, eje y motor visibles, LIDAR |
| Tronco | 1.7.2 | Collar con U delantera abierta y discos de cadera, núcleo hasta Z 300 |
| Cintura | 2.3.0 | Tres piezas; bloque inferior con fondo en arco R70 y eje hueco de cadera |
| Pecho | 3.0.0 | 327 mm, ROG Ally X a la vista, rejillas, aro fino del hombro |
| Cuello | 2.0.0 | Base, cuello 72 mm, collarín |
| Cabeza | 4.2.1 | 175 mm, hueca, visor acrílico, iPhone 12 Pro Max volteable, guías, servo |
| Brazos | v14 | `Toreto_Brazo_Mano_v14` (izquierdo por simetría + `juntas_espejo`) |

**Cadera:** eje en X a Z 400, **libre hasta 85°** (modo `cadera`). Falta el
motor (ahora de tornillo sin fin) y que gire de verdad en Fusion.

### Decisiones (todo en `docs/DECISIONES.md` y `docs/CINEMATICA.md`)

- Ally X en el pecho a la vista; iPhone 12 Pro Max en la cabeza con giro tipo
  libro; encendido de la Ally por USB desde el microcontrolador.
- Brazo: hombro 2 + codo 1 + muñeca 2, **1 kg por mano**, pares mínimos.
- **Motores (cambio del 3 oct):** las cicloidales impresas con NEMA17 dan
  ~3-10 N·m reales (Hackaday): no valen para hombro (15) ni cadera (~30-60).
  → **Tornillo sin fin** (tipo limpiaparabrisas, 20-45 N·m, no giran sin
  corriente) para **cadera y hombro subir/bajar ×2**, con driver BTS7960 y
  AS5600 en el eje. Elevalunas / motores de asiento (5-15 N·m) o cicloidal
  impresa para rotación del brazo, codo y giro de cintura. Muñeca y mano:
  servos y micromotores. Descartados para la cadera: actuador lineal (no
  cabe) y muelle de gas (el usuario no lo quiere).
- **Desguace:** limpiaparabrisas delanteros (mejor de camión, 24 V; iguales
  entre sí) → cadera y hombros; elevalunas y motores de asiento → brazo y
  cintura; limpiaparabrisas trasero → cuello/cintura. Traer conector con
  cable, probar con batería, fotos con regla.
- **Esqueleto de aluminio** (tío del usuario): placa de base + soportes de
  ruedas, nervios y sujeción de batería; columna partida en la cintura con
  rodamiento de giro; soportes de cadera y eje Ø30; travesaño y soportes de
  hombros; soportes de rotación del brazo; espinas de brazo y antebrazo;
  placa del cuello; escuadras. ~5,5 kg.
- Batería LiFePO4 24 V ~15 Ah (~384 Wh) en la base, 5 h; carga a mano con
  sitio para contactos. Bus CAN, canal central, rejillas, ejes huecos.
- Giros deseados de cada articulación; cadera mecánica 85°, software 30°.
  RPLIDAR C1 se mantiene.
- **Fuera del robot:** servidor Proxmox 24/7 con las piezas DDR4 que sobren
  al cambiar de PC (4 × 8 GB Corsair Vengeance LPX, fuente Corsair 850 W
  Gold, SSD 500 GB, 2 discos NAS de 4 TB en espejo); torre con RTX 5080 +
  4070 Ti para IA pesada y simulación, encendida por Wake-on-LAN.

### Compras pendientes (no de aluminio)

Motores de desguace o nuevos; drivers BTS7960; sensores AS5600; motores de
ruedas mecanum (37 mm con reductora, no de desguace); batería LiFePO4 con
BMS (comprobar medidas antes); tornillería inoxidable M3-M5; rodamientos
(2 × 6006 cadera, 2-4 hombros); rodamiento de giro de la cintura tipo
"lazy susan" 100-150 mm con agujero central; "optical endstop" y lámina
antideslizante (o desmontar la Epson WF-2820); servo MG90S del iPhone.

### Pendiente, por orden

1. Lunes: resultado del desguace y del tío → motores reales y aluminio.
2. Diseñar en Fusion soportes, acoples y esqueleto con los motores reales;
   lista de corte v1 con taladros (y DXF).
3. Cadera y hombros como articulaciones reales en Fusion.
4. Medir en la Ally: posición de los mandos; si arranca sola con corriente.
5. Cabeza: que el script conserve nombre y opacidad del visor.
6. Más adelante: límites reales de giro, masas reales → vuelco (desbloquear
   la cadera > 30°), servidor Proxmox, software/ROS 2.

### Cómo trabajamos (lo que funciona)

- **Lienzo = medidas, render 3D = forma.** Medir por píxeles, no a ojo.
- **Plan antes de tocar código**; el usuario aprueba; luego se implementa.
- Comprobar fuera de Fusion antes de pedir ejecutar: compilar y Fusion
  simulado (`scratchpad/sim_*.py`), o simulación geométrica en Python con
  giros. Los lofts solo se prueban en Fusion.
- Cada cambio de un complemento sube su VERSION y se copia a
  `%APPDATA%\Autodesk\Autodesk Fusion 360\API\Scripts\`.
  `work/Toreto_Prueba_Holguras_01_44` está enlazado directo al repo.
- Pruebas en el montaje, SOLO LECTURA, con `Toreto_Prueba_Holguras_01_44`:
  `comprobar`, `cadera`, `alturas`, `interferencias`; leer los JSON.
- Al abrir una carcasa hueca, cerrar siempre el interior.
- **Buscar en web/foros antes de fijar componentes** (el 3 oct una búsqueda
  cambió la elección de motores); precios siempre "orientativos".
- **Documentos para terceros** (taller, su tío): PDF A4 imprimible en
  `docs/fabricacion/`, **sin precios, sin GitHub ni datos de contacto, solo
  lo que esa persona hace** (p. ej. solo aluminio). Generar con Edge
  headless desde HTML.
- Commits sin co-autor; push cuando el usuario lo pide.

## 0. Histórico (29 sept – 2 oct)

**EJECUTADO (29 sept): cuello–pecho como en el lienzo.** Pecho 25 cuerpos
(Z 540–737,8), cuello 3 cuerpos; modo `alturas` sin cambios (pecho→cuello
−7,86). Revisado: interior cerrado; el anillo de la cabeza no se ve.
Pecho 2.8.0 EJECUTADO: tapa negra que rellena el rebaje hasta Z 722 y disco
de 97 mm en 722-730 (forma del render 3D; el render vale para forma, no
para medidas).
**EJECUTADO: Pecho 2.9.0 + Cintura 2.0.0 + Tronco 1.4.0** (tronco 7
cuerpos, cintura 11, pecho 25 en Z 520–737,8; alturas: tronco→cintura
−36,04 y cintura→pecho −20,02, como se esperaba). Revisión visual: el
tronco hueco se veía por la silla (mismo fallo que el pecho).
**Cabeza 4.1.2 EJECUTADA y aceptada** (13 cuerpos; los ojos serán dibujo de
la pantalla, no importa que asomen 1,2 mm): el visor
plano sobresalía como una losa (el frente es curvo: a 107 mm del centro
está 17 mm atrás) y el hueco de la pantalla rompía las esquinas. Visor
214×128 R30 y pantalla 200×114 R24 enrasados (zona delantera de la propia
carcasa), ojos pegados a la cara, sin hueco interior (Waveshare en fase 2).
**Tronco 1.6.1 EJECUTADO y aceptado** (9 cuerpos): panel frontal sobre el LIDAR, piel
de 1,5 mm que sigue el cono, 82 mm de ancho, R9, Z 228-310 (lienzo).
Cabeza 4.1.0 EJECUTADA (14 cuerpos). **Cabeza 4.1.1 EJECUTADA** (13, dorso
liso): sin tapa posterior (con el dorso redondo solo asomaban
sus esquinas). Antes, 4.1.0: loft de 17 secciones con esquinas
redondeadas reales (frente 264×160 R40, frente del lateral R15, dorso R75)
en vez de las 9 que hacían un "tejado" con arista. Primer intento: la
carcasa salió bien pero el loft del bisel (sin tocar, de la 4.0.0 de Codex)
falló por autointersección; probablemente la 4.0.0 nunca llegó a ejecutarse
entera. Bisel y pantalla pasan a rectángulos redondeados (R35/R28).
**EN CURSO (1 oct): fase 2, maqueta `Toreto_Maqueta_Ally_Pecho` 1.2.0**
(complemento aparte, componente 90_MAQUETA_ALLY_PECHO; para verla ocultar
04_PECHO_HOMBROS y 06_CABEZA): pecho 321 mm con la Ally X a la vista,
reductoras Ø60 + NEMA17 del hombro, iPhone 12 Pro Max con giro tipo libro,
zonas reservadas de cables y aire. Choques en maqueta_ally_pecho.json.
Ver `docs/DECISIONES.md` (propuesta Ally/iPhone, cables y calor, requisitos
del brazo: 1 kg por mano, hombro 2 + codo 1 + muñeca 2, reductoras
impresas, prototipo del hombro con opción A NEMA17 + MKS SERVO42D).
Decidido el 1-2 oct (todo en DECISIONES.md y CINEMATICA.md): Ally en el
pecho (327 mm), iPhone volteable en la cabeza (+15 mm, robot ~965 mm),
batería LiFePO4 24 V ~384 Wh en la base (5 h, carga a mano con sitio para
contactos), giros deseados y cadera nueva (actuador lineal, mecánica 85°,
software 30°). **Pecho 3.0.0 EJECUTADO (2 oct):** 327 mm, Ally X a la
vista, rejillas, aro fino; 29 cuerpos; modo nuevo `comprobar` (alturas +
interferencias): pecho→cuello −0,03, 0 choques brazos-resto. La maqueta
90_MAQUETA ya no hace falta. **Cabeza 4.2.1 EJECUTADA (2 oct):** 175 mm
(Z 790-965), hueca 3 mm (segundo loft), marco + visor de acrílico como piel
de 3 mm, iPhone 12 Pro Max ~9 mm tras el visor (el frente se curva: más
adelante sus extremos se salían) en modo cara arriba con los ojos, guías en
semicírculo, servo MG90S detrás del barrido, rejilla trasera; 16 cuerpos;
comprobar: cuello→cabeza −0,04, 0 choques. Fallo conocido: Fusion no
conserva el nombre del visor (sale "Cuerpo…") ni la opacidad del script;
puesta a mano (30 %). Siguientes: la cabeza
(175 mm), diseñar la cadera, y el prototipo del hombro (opción A).
Aparcado: desmontar la Epson WF-2820 (negro atascado) para sensores ópticos
y goma de yemas; si no, comprar "optical endstop" y lámina antideslizante.

**HECHO (30 sept): brazo v14 en el montaje.** `Toreto_Brazo_Mano_v14`
reemplazó al v13c (derecho; el izquierdo por simetría), juntas_espejo: 20
juntas y 16 relaciones (peor pasador 0,001 mm); alturas iguales; modo nuevo
`interferencias` (solo lectura): 0 choques brazos-resto (212 × 144 cuerpos).
Con esto el exterior queda igualado al lienzo y al render. SIGUIENTE: fase 2
(qué piezas lleva y dónde). Detalle del brazo v14: (`MODE='ver_brazo'` en `Toreto_Prueba_Holguras_01_44`):
cápsula blanca del hombro R55 (antes R45), cara exterior recortada plana
(R60) para que el tramo inclinado no tape el disco, disco negro R45×3 +
escalón R20×2 unidos a la tapa del eje (que ahora acaba en la cara), y
`_appearance` crea los colores si faltan. Primera ejecución OK (tapa y
rótula a 0,0 mm; blanco/negro bien); el usuario pidió la parte alta como la
cápsula redonda del render: por encima del eje se quita todo lo que esté a
más de R55 del eje (tapa semicircular concéntrica al disco). Simuladores y 20 pruebas OK
(test_arm_pose actualizado a v14). Pasos: documento HÍBRIDO vacío → ejecutar
→ guardar como `Toreto_Brazo_Mano_v14` → en el montaje Reemplazar componente
(brazo derecho) → borrar juntas de la mano izquierda → `MODE='juntas_espejo'`
→ `MODE='alturas'`. Antes estaba aplazado (proceso largo: documento nuevo + Reemplazar +
juntas_espejo): disco negro Ø84 visible en el hombro con aro blanco, y
arreglar el color gris (el script solo aplica "TORETO Blanco satinado" si ya
existe en el documento; en uno nuevo no existe y queda acero por defecto).
Base 2.0.0 EJECUTADA (83 cuerpos; base→tronco −28,94). **Base 2.0.1
EJECUTADA y aceptada**: chasis recortado a R 218 (asomaba del disco), placas de
rueda R 57, pasadores en los rodillos, carcasa de motor redonda Ø44.
Base 2.0.0 (simulada: 83 cuerpos, Z 0-228,9, rodillos tocan Z 0). Planta REDONDA Ø450 (la lámina mide igual
de frente y de lado; antes elipse 450×356), disco blanco Z 160-200 con
chaflán y aro negro en la tapa, cuerpo negro Z 100-160 con arcos, chasis
246 mm Z 31-100, pilares blancos laterales, mecanum Ø148 × 66 con 10
rodillos Ø24 a 45° y dos placas, eje + soporte de motor visibles, LIDAR
adelantado a Y −150 con el pedestal recortado contra el tronco. Decisiones
(DECISIONES.md): mecanum con aspecto del render; hombro con discos del
lienzo. Pendiente después: hombro (cápsula blanca + disco negro exterior),
cabeza redondeada, panel sobre el LIDAR, brazos blancos.

**EJECUTADO y ACEPTADO (29 sept): Tronco 1.6.0 + Cintura 2.2.0**
(alturas: tronco→cintura −60,04, resto igual). Decisión del
usuario: el bloque inferior de la cintura va FIJO y ENTERO por dentro del
tronco (el giro está en la junta de anillos). La 1.5.0 (espiga, tronco
elíptico 0,8) se ejecutó y el bloque asomaba por las esquinas: una elipse
no puede envolver un bloque casi cuadrado. Ahora: cono 200-335 (246→228,
fondo 0,9 medido en la vista lateral) + collar blanco de planta cuadrada
redondeada 212×190 R85 (Z 335-390) cuyo hueco es exactamente el bloque
(182×146 R50, baja a Z 330), silla en U recortada en el collar (fondo 354)
y tapa interior Z 325-335. Alturas esperadas: tronco→cintura **−60**.
Antes: Tronco 1.4.1 (8 cuerpos) + Cintura 2.0.1 ejecutados; silla de radio 40 y
bloque inferior de radio 36 (fondo plano ±55 como el lienzo) y relleno
blanco 08_RELLENO_SILLA_BLANCO (Z 346-390) que cierra el interior. Ejecutar
Tronco → Cintura → alturas (debe seguir igual). **Lección:** al abrir una
carcasa hueca, cerrar siempre el interior con un relleno. Pecho con falda hasta Z 520;
cintura en 3 piezas (bloque superior 170×136 Z 470-540 con conector redondo
en cada costado; junta de anillos Ø128 Z 460-470; bloque inferior 182×146
Z 354-460 con franja y panel 74×70); tronco con borde en silla (Z 390 en
los costados, 350 delante y detrás) y sin collar negro. Ejecutar Tronco →
Cintura → Pecho → alturas. **Solapes nuevos a propósito:** tronco→cintura
−36 y cintura→pecho −20. Siguiente diferencia: cabeza redondeada (render). Pecho 2.7.0
(rebaje en U de 135 mm con fondo en Z 700, abierto por delante y cerrado a
30 mm de la trasera; asiento negro de 6 mm que tapa el interior; copa negra
de 97→73 mm en Z 700-730) y Cuello 2.0.0 (base 97→83 en 730-749, cuello de
72 en 749-763, collarín de 94 en 763-790; sin fuelle). Ya copiados a
`%APPDATA%` y comprobados con un Fusion simulado. Ejecutar Pecho → Cuello →
modo `alturas`. Diferencias con el lienzo que quedan (juego de diferencias
del 29 sept; las marcas naranjas del lienzo son las juntas 200/390/541/730/
791): anillo inferior de la cabeza (144 mm, más ancho que el collarín),
falda blanca del pecho que baja ~20 mm sobre la cintura, cintura en dos
bloques, cuna en U arriba del tronco, panel blanco sobre el LIDAR y pantalla
del pecho (el lienzo ~170×118; el Android real 160×90: se decide en fase 2).

**HECHO el 29 sept: montaje de alturas cerrado.** Tronco 200-390, cuello
730-790; `alturas_montaje_v14.json` da los seis módulos en su cota nominal
(0 / 200 / 390 / 540 / 730 / 790 / 950). Juntas tronco→cintura,
cintura→pecho y cuello→cabeza a -0.04 mm (tolerancia de la caja envolvente,
no hueco real). Solapes a propósito: base→tronco -28.9 (torreta LIDAR hasta
228.9) y pecho→cuello -7.9 (conectores de hombro hasta 737.8). Lo siguiente
es la fase 2 (sección 6).

Pasos que se ejecutaron (en `Toreto_hombro_encajado_sin_articulaciones_backup`):

1. Complemento **`Toreto_Tronco_95cm`** (1.3.1) → regenera el tronco con
   `alto_tronco` = 190. Hoy acaba en Z 385 (se hizo con 185) y deja 5 mm de
   hueco bajo la cintura.
2. Complemento **`Toreto_Cuello_95cm`** (1.2.1) → regenera el cuello con
   `alto_cuello` = 60. Hoy acaba en Z 785 (se hizo con 55) y deja 5 mm bajo
   la cabeza.
3. Comprobar con `Toreto_Prueba_Holguras_01_44` en **modo `alturas`** (v14,
   SOLO LECTURA; es el modo activo): tronco→cintura y cuello→cabeza deben dar
   0. Los solapes base→tronco (torreta del LIDAR) y pecho→cuello (discos del
   hombro e inserto del cuello) son a propósito.

Ambos complementos ya están copiados a `%APPDATA%\Autodesk\Autodesk Fusion
360\API\Scripts`. Causa de fondo: los generadores solo se regeneran si cambia
su VERSION; al cambiar parámetros de altura nadie los regeneró. Sigue siendo
un defecto: cualquier cambio de parámetros exige subir la versión.

**Base 1.10.0 y Cabeza 4.0.0 estaban solo en `%APPDATA%`** (cambiadas el 5
sept, probablemente por Codex, sin subir). Copiadas al repo el 29 sept.

**Estado del montaje (29 sept):** pecho 2.6.0 con la pieza de hombro de la
lámina; dos brazos v13c (`Toreto_Brazo_Mano_v13c`, el izquierdo por Crear >
Simetría) con el hombro coaxial con el conector del pecho; las dos manos de
4 motores articuladas (la izquierda con `MODE='juntas_espejo'`). Interferencia
brazo-pecho limpia y sin huecos en el hombro.

**Siguiente, por orden del usuario:** montar entero (HECHO 29 sept) → **qué piezas lleva y dónde** (fase 2: sección 6) → dimensiones
reales → límites de articulaciones. Propuesta pendiente de decidir: brazo con
hombro 2 + codo 1 + muñeca 2 movimientos, y los 4 motores de la mano.

**Pendientes conocidos del montaje:** rótula de la muñeca asignada al
antebrazo (debería ir con la mano); palma sin recortar contra las primeras
falanges; piezas del pecho embutidas entre sí (algunas a propósito).

**Lecciones de estos días:** una interferencia limpia no prueba que las
piezas estén unidas (mirar huecos); al cambiar el brazo derecho la simetría
se recalcula sola y hay que borrar las juntas de la mano izquierda y volver
a ejecutar `juntas_espejo`; medir alturas con el modo `alturas` en vez de a
mano; y antes de fiarse de un complemento, comparar la copia de `%APPDATA%`
con la del repo.

> **Documento de relevo. Leerlo entero antes de tocar nada.**
> Sustituye a la versión del 13 de septiembre, que mandaba trabajar sobre el
> documento abierto en Fusion y reparar la mano con parches sucesivos. Ese
> método se abandonó: produjo unas 38 versiones sin converger.

## 1. Dónde estamos

- **La mano funciona en el ensayo de colisiones por primera vez.** Mano
  adaptativa de cuatro motores; la v8 salió *todo limpio y pinza del boli
  lograda*. Guardada en GitHub (commit `4eab5e7`).
- **No es una mano validada.** Faltan palma, holgura continua, resistencia,
  agarre de objetos, tendones, y comprobar si la pinza toca por la yema.
- **Pinza vista en 3D (v9, 26 sept noche):** el pulgar toca de punta. El
  usuario decidió que el índice está bien y que el **pulgar debe apoyar con
  la cara plana de su última falange** (sección 5.1).
- **Pinza del boli CERRADA (27 sept):** pinza lateral, ensayada con sólidos
  (v10/v10b) y vista en 3D: cara plana del pulgar contra la esquina
  redondeada de la punta del índice, V de 20-30°, sin choques antes del
  contacto. El usuario la aceptó (`docs/DECISIONES.md`).
- **Brazo v11** (`fccfe50`): medidas y postura de la lámina, verificado en
  Fusion. **Orden decidido por el usuario:** montar el robot entero →
  qué piezas lleva → dimensiones reales → y solo entonces límites.
- **El montaje BUENO es el documento de Fusion
  `Toreto_hombro_encajado_sin_articulaciones_backup`** (confirmado por el usuario
  el 27 sept; no `00_Toreto_Ensamblaje_95cm` ni el que no lleva `_backup`).
  Estado al 27 sept: dos brazos v13 con el hombro encajado y las dos manos
  articuladas (commit `5c7654d`). Antes, en el documento sin `_backup`:
  todos los módulos más UN brazo, el de prueba antiguo (`94_BRAZO_MARCOS_LOCALES…`).
  El conector de hombro del pecho (`07_CONECTOR_HOMBRO_DER`, complemento
  Pecho_Hombros 2.5.0) queda en X 166-196,5, Y 0, Z 690,8, radio 36,5 mm:
  a la altura del pivote del v11 (Z 690), con 16 mm de diferencia en Y.
- La fase 2 (componentes) sigue casi toda abierta: sección 6.

## 2. Cómo trabajamos — el método que ha funcionado

Esto es lo más importante del documento. La v7 y la v8 salieron bien a la
primera en Fusion tras un mes de intentos fallidos, y fue por el método.

1. **Plan antes de actuar.** Explicar qué se va a hacer, en qué archivo y
   por qué, y esperar el "sí" del usuario. Lo pidió literalmente: *"antes
   de hacer nada dime qué harías"*.
2. **Diagnosticar en los datos antes de parchear.** Si algo no converge,
   parar y analizar el resultado (qué pares chocan, en qué muestra, cuánto),
   no proponer otro parche. Así se vio que el ensayo antiguo exigía algo
   imposible (sección 3).
3. **Validar fuera de Fusion antes de pedir una ejecución.** Pruebas
   unitarias y, si el flujo es nuevo o cambia, `simular_sin_fusion.py`, que
   recorre el ensayo entero con un Fusion falso. Cada ejecución en Fusion es
   tiempo real del usuario; una que falla por un error de programación es
   una ejecución tirada.
4. **Cambios pequeños, justificados con datos ya medidos, uno por
   ejecución.** Ejemplo: el índice al 90% de recorrido, porque ese tramo ya
   lo había medido limpio la v7.
5. **Aislamiento total.** El ensayo solo corre en un documento de Fusion
   vacío (se niega si hay cuerpos), trabaja con sólidos temporales, no
   publica nada y no toca el robot original.
6. **Decir lo que no se ha comprobado.** Un error del núcleo geométrico
   nunca cuenta como "sin choque". No llamar "funcional" a nada que no se
   haya validado. Cada informe lista lo que queda fuera.
7. **El usuario ejecuta en Fusion; Claude lee el JSON.** No controlar la
   interfaz de Fusion. Sí se puede capturar su ventana en modo solo lectura
   si el usuario pide revisar su estado.
8. **Documentar cada resultado el mismo día:** `RESULTADO_PRUEBA.md`
   (cronología), README de la prueba, `docs/DECISIONES.md` y
   `docs/ROADMAP.md` para decisiones, `docs/CUADERNO.md` (privado) para la
   trastienda.
9. **Git:** commits sin línea de co-autor (regla general del usuario);
   `git add` con rutas explícitas; push solo cuando el usuario lo pide.
10. **Componentes antes que mecánica** (regla del proyecto, `DECISIONES.md`).
    La mano no convergía en parte por diseñar bisagras y holguras sin saber
    qué iba a mover los dedos.

## 3. La mano: decisión, resultado y por qué ahora sí

**Decisión (26 sept, en `docs/DECISIONES.md`):** mano adaptativa de cuatro
motores, con tendones y muelles de retorno, motores en el antebrazo. El
usuario quiere agarres humanos: boli con pulgar e índice, pelota pequeña,
vaso, cualquier objeto dentro de 300-500 g.

| Motor | Articulaciones |
|---|---|
| Índice | `JUNTA_DEDO_1_1..4` (`DEDO_1` es el índice: base a 55 mm del pulgar) |
| Corazón + anular + meñique | `JUNTA_DEDO_2..4_1..4` |
| Flexión del pulgar | `JUNTA_PULGAR_2..4` |
| Rotación del pulgar | `JUNTA_PULGAR_1` (el cardán) |

**Por qué no convergía antes:** el ensayo cerraba los cinco dedos a la vez
hasta el final. En la v6, 55 de 58 choques estaban en el tramo final y el
87% del volumen era pulgar contra puntas. Ninguna mano con pulgar oponible
cierra así sin que el pulgar entre en los dedos; recortar material no podía
resolverlo.

**Ensayo actual (desde la v7):** mano abierta; cada motor solo, con criterio
de cero choques; y la pinza del boli.

| | v6 | v7 | v8 |
|---|---|---|---|
| Pares en colisión | 58 | 1 | **0** |
| Pinza del boli | — | al 67% | **al 83%, punta con punta** |

La v7 incluyó la corrección del taladro que dejó sin probar la sesión
anterior (limpió la mano abierta). La v8 bajó el recorrido del índice al
90% (54/54/45/36° en vez de 60/60/50/40), en cinemática y en topes físicos.

## 4. Archivos y cómo ejecutar

Todo en `work/Toreto_Prueba_Holguras_01_44/` (versionada en git):

- `toreto_hand.py` — generador de la mano. Límites: `MAIN_FLEXION_LIMITS_DEG`,
  `INDEX_FLEXION_LIMITS_DEG`, `THUMB_FLEXION_LIMITS_DEG`, `finger_flexion_limits()`.
- `toreto_motor_groups.py` — reparto de motores y escenarios. Sin Fusion.
- `toreto_motor_validation.py` — ensayo histórico de la v8.
- `toreto_lateral_validation.py`, `toreto_contact_faces.py` — ensayo aislado
  y clasificación del primer contacto de la v10.
- `Toreto_Prueba_Holguras_01_44.py` — script de Fusion. Modo activo:
  `ensayo_lateral`; si se ejecuta escribe `prueba_mano_4_motores_v10.json`.
- `test_clearance.py`, `test_motor_groups.py`, `test_lateral_pinch.py` —
  33 pruebas.
- `simular_lateral_sin_fusion.py` — v10 con Fusion falso; el simulador
  inventa choques, no valida la geometría.
- `RESULTADO_PRUEBA.md` — cronología de todos los ensayos, con rechazos.

**Ejecutar en Fusion:** en un documento **vacío de diseño híbrido** (uno de
pieza falla: solo admite un componente), Utilidades > Complementos >
`Toreto_Prueba_Holguras_01_44` > Ejecutar. Este script está registrado
apuntando a esa carpeta del repo: los cambios se ven sin copiar nada.

**Pruebas:** desde esa carpeta, `python -m unittest discover -s . -p "test_*.py" -v`
**Simulación v10:** `python simular_lateral_sin_fusion.py`

## 5. Pendiente de la mano, en orden

1. **Pinza del boli: hecha y aceptada** (v10b; ver `RESULTADO_PRUEBA.md` y
   `ESTUDIO_APOYO_PLANO.md`). Queda pendiente en el script forzar el
   recálculo tras la pose: Fusion guarda los valores de las juntas pero no
   mueve las piezas hasta que se acciona una junta a mano.
   **Agarre de vaso** (propuesto, sin empezar): cilindro simulado de 60-80
   mm, cada falange se detiene al tocarlo.
2. **Prueba de la palma** (`06_PALMA_Y_CONECTOR`, hoy excluida). Primero
   medir, como diagnóstico, cuánto invade cada motor la palma; recortar solo
   después, y con los controles de siempre.
3. **Agarres con objeto simulado:** vaso y pelota, deteniendo cada dedo al
   tocar el objeto (es lo que hace una mano adaptativa).
4. **Canales de tendón, anclajes y muelles de retorno.** El diseño no los
   tiene todavía.
5. **Holgura continua** entre posturas y **resistencia.** Pasadores y
   paredes: ¿el pasador de 2,8 mm será impreso o metálico? Impreso es frágil.
6. **Trasladar la mano al robot real** (`00_Toreto_Ensamblaje_95cm`), solo
   cuando esté validada.

## 6. Pendiente del resto del proyecto

**Plan general del usuario:** (1) la forma igual que los lienzos en Fusion;
(2) decidir qué mecanismos llevan y dónde; (3) agrandar o reducir según las
piezas, manteniendo la forma.

**Fase 2 — componentes** (`docs/ROADMAP.md`, v0.2):
- Los **4 motores concretos de la mano** — con su peso se dimensionan
  hombro y codo.
- Servos de hombro y codo; resto de servos del brazo; cuello de 2 DOF.
- Motores y encoders de la base (4 ruedas mecanum).
- Batería y alimentación. Requisito duro: **65 W por USB-C PD** para la Ally.
- **Microcontrolador de seguridad**: casi obligatorio, porque el ordenador
  principal (la Ally) es extraíble.
- Lista de compra con precios reales.

**Ya decidido:** todo local sin nube; ordenador de a bordo ROG Ally X Z2
(ya en propiedad) en bahía extraíble; RPLIDAR C1; cámara con IA integrada
tipo OAK-D; mano de 4 motores.

**Acordado en conversación, sin documentar todavía:**
- **Cara con el iPhone 12 Pro Max** del usuario (tiene el cable), con una
  **app iOS** que se conecta a la Ally y dibuja la cara. Un iPhone no acepta
  vídeo de entrada: hace falta la app. Su LiDAR no sustituye a la cámara.
- **Dónde va la Ally: reabierto.** `DECISIONES.md` dice base. El usuario
  prefirió el pecho, pero la lámina mide la carcasa del pecho en ~252 mm y
  la bahía necesita ~300 mm: no cabe sin cambiar la silueta. Se decide en el
  paso 2 del plan general.

## 7. Por rectificar (inconsistencias conocidas)

1. `docs/CINEMATICA.md` describe una "pinza de 3 dedos" prismática. Debe ser
   la mano de 5 dedos: 16 articulaciones de dedo + 4 de pulgar, 4 motores.
2. `docs/DECISIONES.md`:
   - documentar la cara con iPhone y la app iOS;
   - marcar como reabierta la ubicación de la Ally;
   - la entrada "La tabla de cotas Z no se fija todavía" choca con que los
     parámetros de Fusion ya se ajustaron a la lámina el 29 ago
     (`218b933`): aclarar que la forma exterior ya sigue la lámina y que lo
     pendiente son los ajustes por componentes.
3. `docs/ROADMAP.md` v0.3 no refleja el trabajo de septiembre (brazos,
   manos, cabeza, base y ruedas alineados con los lienzos: unos 22 commits).
4. **7 carpetas de scripts fallidos sin commitear** en
   `cad-toreto/toreto_fusion_95cm/fusion_scripts/`: `Toreto_*_01_38` a
   `01_43` y `Toreto_Reparar_Mano_95cm`. Decidir si se archivan en git como
   historial o se borran. En total hay 22 add-ins; conviene ordenarlos.
5. Los **5 módulos OpenSCAD** de `toreto_exterior_95cm` no se alinearon con
   la lámina (solo Fusion). Según `DECISIONES.md` Fusion sustituye a
   OpenSCAD: decidir si se actualizan o se marcan como históricos.
6. **Add-ins duplicados** entre el repo y
   `%APPDATA%\Autodesk\Autodesk Fusion 360\API\Scripts\`, sincronizados a
   mano. Solución: registrarlos en Fusion apuntando a la carpeta del repo,
   como ya pasa con `Toreto_Prueba_Holguras_01_44`.
7. La **captura de "forma aprobada"** del 13 sept vivía en `%TEMP%` y se
   perdió. Buscar otra copia.

## 8. Trampas conocidas

- **La carpeta buena es `C:\Users\tarif\Desktop\Robot-Toreto\cad-toreto`.**
  Hay dos hermanas que NO son el proyecto: `cad-toreto-gpt` (rama de 65 cm
  descartada) y `C:\Users\tarif\Desktop\cad-toreto` (taller de Codex del 5
  sept; sus lienzos son idénticos, pero no manda).
- **No guardar nada importante en `%TEMP%`**: ya se perdieron así la lámina
  (recuperada) y la captura de forma aprobada.
- `.gitignore` ignora `work/*` salvo `work/Toreto_Prueba_Holguras_01_44/`.
  Si se crea otra carpeta de trabajo que haya que versionar, añadir su
  excepción: si no, sus archivos nuevos serán invisibles para git.
- En este proyecto trabaja en paralelo **otra IA (Codex)**, con commits en
  inglés a nombre del usuario. Antes de empezar, revisar `git log` y
  `git status`: puede haber cambios nuevos o archivos modificados en disco.
- El documento de Fusion de pruebas se llama `Sin título` y debe estar
  **vacío**. No se guarda.

## 9. Lo subido a GitHub en este periodo

- **26 ago:** lámina calibrada; herramienta de medición de cotas Z; fix del
  add-in de referencias; README al día; STL de 26 MB a Git LFS (reescribió
  el historial); IA todo local; RPLIDAR C1 + cámara tipo OAK-D;
  transformación de lienzos por plano.
- **29 ago:** Ally X Z2 en bahía extraíble, con cotas confirmadas;
  `measure_silhouette.py`; parámetros de Fusion ajustados a la lámina;
  perfiles exactos (`extract_profiles.py` y add-in `Toreto_Perfiles_95cm`).
- **30 ago – 7 sept (Codex):** parámetros maestros sincronizados; pecho;
  palma y manos; brazos, cabeza, base y ruedas alineados con los lienzos.
- **26 sept:** `37c07de`, punto de control de la reparación de la mano
  (Codex); `4eab5e7`, mano de 4 motores v7/v8, decisión documentada y
  `.gitignore`; y este documento con `simular_sin_fusion.py`.

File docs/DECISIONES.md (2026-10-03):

# Decisiones del proyecto

Registro de decisiones que no se deducen del código ni del CAD, para no depender
de memoria de chat. Se añade una entrada nueva cuando se cierra algo importante;
las anteriores no se editan, solo se marcan como superadas si cambia.

## Orden de trabajo: diseño → componentes → CAD

Tres fases, en este orden, sin saltárselo:

1. **Diseño** — cerrar forma, proporciones y módulos.
2. **Componentes** — elegir batería, servos, motores, LIDAR, cámara y procesador.
3. **CAD y materiales** — medidas definitivas y material pieza a pieza, con los
   componentes ya en la mano.

Ninguna cota es definitiva hasta tener los componentes físicos. Por eso el CAD
va al final, no al principio.

**Estado actual: fase 1 (diseño).**

## Diseñar contra la referencia, no contra el CAD anterior

La imagen de referencia (`docs/referencia_infografia.png` si se añade) es la
especificación, no un punto de partida aproximado. Al iterar el diseño no se
reutiliza geometría de versiones previas — se parte de cero y se compara
directamente contra la referencia.

## Fusion sustituye a OpenSCAD (a partir de fase 3)

OpenSCAD sirve para maquetas visuales rápidas (fase 1), pero el CAD final de
fase 3 se hace en **Autodesk Fusion**, por dos motivos concretos:

- Ensamblaje con **articulaciones reales y topes** — el brazo se arrastra con
  el ratón para validar alcance y colisiones, en vez de escribir ángulos a
  mano y renderizar cada vez.
- El plugin **URDF Exporter** convierte ese ensamblaje en el modelo cinemático
  que consumen ROS 2 y Gazebo.

Stack mínimo del proyecto: Fusion, Bambu Studio, NotebookLM, KiCad o AutoCAD
Electrical, ROS 2 + Gazebo, GitHub.

Impresión: más perímetros antes que más relleno — 4-5 paredes con giroide al
25-30 %, en una Bambu Lab P1S (volumen 256 × 256 × 256 mm).

## IA local o en la nube — cerrada: todo local, Jetson Orin Nano (26 ago 2026)

> **Parcialmente superada el 29 ago 2026** por la entrada
> "[Ordenador de a bordo: ROG Ally X Z2 en bahía extraíble](#ordenador-de-a-bordo-rog-ally-x-z2-en-bahía-extraíble-29-ago-2026)".
> Sigue vigente lo esencial —**todo local, sin nube**—; lo que cambia es
> *qué máquina* lo ejecuta.

Decisión que bloqueaba el resto de la fase 2. Se barajaron tres opciones
(nube con Raspberry Pi 5, mixto con Pi 5 + LIDAR local para el reflejo de
emergencia, y todo local con Jetson) y el usuario eligió **todo local**:

- **Ordenador de a bordo único: NVIDIA Jetson Orin Nano** (Super Developer
  Kit o equivalente — modelo exacto y precio real quedan para la lista de
  compra). No hace falta Raspberry Pi adicional: el Jetson hace de único
  computador de a bordo.
- Funciona sin conexión a internet y responde al instante, tanto para la
  conversación como para la detección de obstáculos/parada de emergencia.
  No se usa Gemini/Google AI Pro para la IA embarcada del robot (sigue
  disponible para todo lo demás del proyecto que ya lo usa).
- Coste más alto que la alternativa nube (~250 € frente a ~80 € de una
  Raspberry Pi, cifras aproximadas de agosto 2026 — verificar en la lista de
  compra real) y más consumo, asumido a cambio de funcionar sin red y sin
  depender de servicio externo.

**Pendiente para cuando se elijan motores/encoders de la base:** decidir si
el control de motores y la parada de emergencia por hardware corren
directamente en el Jetson (Linux, sin tiempo real garantizado) o si conviene
un microcontrolador aparte (Arduino/STM32/ESP32) dedicado a esa parte
crítica — no es lo mismo IA local que control en tiempo real, y el Jetson
resuelve la primera pero no necesariamente la segunda.

## Ordenador de a bordo: ROG Ally X Z2 en bahía extraíble (29 ago 2026)

> **Superada el 1 oct 2026** en cuanto a la ubicación: la Ally va en el
> pecho, a la vista (ver "Ally en el pecho, iPhone en la cabeza"). Sigue
> vigente que es el ordenador de a bordo y todo local.

El usuario **ya tiene** una ASUS ROG Ally X con Ryzen AI Z2 Extreme. Pasa a
ser el ordenador de a bordo, en lugar del Jetson Orin Nano de la entrada
anterior. Lo esencial de aquella decisión no cambia: **todo local, sin
nube**. Cambia la máquina.

**Por qué:** ya está pagada (frente a ~250 € del Jetson), y sus 24 GB de RAM
frente a los 8 GB del Orin Nano dan margen real para un LLM local de
conversación decente. Se pierde el ecosistema NVIDIA (CUDA, TensorRT, Isaac
ROS), que es el estándar de facto en robótica — pero la cámara elegida (tipo
OAK-D) hace su propia inferencia de visión a bordo, que es justo donde ese
ecosistema era imbatible.

**Dónde va: en la BASE, no en el pecho.** Medido contra la geometría real de
`base_exterior_95cm.scad` (no a ojo): alineada con el eje X caben hasta
**300 × 130 × 55 mm**, y sobran unos 80 mm de altura por encima. Los huecos
de rueda están a ±45°/135°/225°, así que los ejes X e Y apuntan a los
espacios *entre* ruedas, donde cabe bastante más que el cilindro central
libre (⌀260 mm). En el pecho solo entraba en una orientación, sin holgura y
ocupándolo entero — además de subir el centro de gravedad ~700 g, que con
base holonómica de mecanum se nota al acelerar.

**Formato: bahía extraíble**, no empotrada. Se desliza dentro de la base con
un único conector USB-C (alimentación + datos) y se saca cuando el usuario
quiera usarla como consola. Se descartó empotrarla permanentemente: es el
componente más caro del robot y perderla como portátil no compensa la
simplificación mecánica.

### Consecuencias abiertas, para no perderlas de vista

1. **La parada de emergencia ya no puede vivir en el ordenador principal.**
   Si el cerebro se puede extraer físicamente, un reflejo de seguridad que
   dependa de él desaparece al sacarlo. Esto convierte el microcontrolador
   dedicado (Arduino/STM32/ESP32) —que la entrada anterior dejaba como
   "quizá"— en prácticamente obligatorio, y con él la pregunta de qué debe
   seguir funcionando con la bahía vacía: ¿el robot queda inerte pero
   seguro, o mantiene movimiento básico?
2. **Térmica y ventilación**: está diseñada para disipar al aire libre, en
   las manos. Dentro de una carcasa cerrada necesita conducto propio, y
   **tiene que salir hacia arriba** (ver cotas confirmadas más abajo: por
   los lados solo quedan ~2 mm, por arriba sobran ~68 mm).
3. **Dos baterías**: la Ally lleva la suya (80 Wh). Puede ser una ventaja
   (dominio eléctrico independiente) o una complicación de gestión. Su
   cargador es de **65 W (20 V / 3,5 A)**, lo que fija un requisito duro
   para la arquitectura de alimentación, todavía sin cerrar: la base tiene
   que poder entregar 65 W por USB-C PD de forma sostenida.
4. **Duplicidades que conviene revisar antes de comprar nada.** La Ally trae
   pantalla táctil de 7" 1080p, altavoces estéreo, matriz de micrófonos con
   cancelación por IA e IMU de 6 ejes. Metida en la base:
   - la **IMU** queda justo donde debe estar la de un robot (`base_link`) —
     ganancia limpia, un componente menos que comprar;
   - la **pantalla, los altavoces y los micrófonos** quedan enterrados e
     inservibles, mientras el diseño de la cabeza prevé comprar *otra*
     pantalla de 7" (Waveshare) y el robot necesitará micro y altavoz en la
     cabeza de todas formas. La duplicidad de pantalla es la más llamativa:
     conviene decidir a conciencia, no por inercia.

### Cotas confirmadas (29 ago 2026)

Ficha oficial aportada por el usuario: **290 × 121 × 27,5–50,9 mm, 715 g**,
batería 80 Wh, cargador 65 W, **dos puertos USB-C** (uno USB4/Thunderbolt 4
con DP 2.1 y PD 3.0; otro USB-C 3.2 Gen2 con DP 2.1 y PD 3.0), Wi-Fi 6E y
Bluetooth 5.2.

Los dos USB-C resuelven el reparto limpiamente: uno para alimentación (PD
desde la batería del robot), otro para el hub de periféricos (LIDAR, cámara
y microcontrolador). No hace falta ningún adaptador extra.

Envolvente libre medida en `base_exterior_95cm.scad`, alineada con el eje X:

| Eje | Aparato | Bahía (+2 mm holgura, +3,2 mm pared) | Límite real | Margen |
|---|---:|---:|---:|---|
| Ancho (X) | 290 mm | 300,4 mm | >320 mm | holgado |
| Fondo (Y) | 121 mm | 131,4 mm | ~134 mm | **~2 mm — crítico** |
| Alto (Z) | 50,9 mm | 61,3 mm | ~130 mm | ~68 mm libres |

**Cabe montada, sin desmontar nada.** El fondo es la cota que manda; el
ancho y el alto sobran. De ahí que la ventilación tenga que ser vertical.

**Nota de método:** es el primer componente físico que existe de verdad en
el proyecto. Por la regla de [orden de trabajo](#orden-de-trabajo-diseño--componentes--cad),
es también la primera restricción interna real, y por tanto lo primero que
empieza a desbloquear la tabla de cotas Z que sigue congelada.

## LIDAR y cámara RGB-D — cerrada (26 ago 2026)

- **LIDAR: RPLIDAR C1** (Slamtec) — 12m de alcance, montado en la base,
  familia con soporte ROS2 oficial (`rplidar_ros`), estándar de facto en
  los tutoriales de Nav2. Se prefirió sobre el A1M8 (más barato, ~8m) por
  el margen de alcance.
- **Cámara: con IA integrada, categoría tipo OAK-D** (Luxonis) — la propia
  cámara procesa parte de la visión (detección, quizás profundidad) antes
  de mandar datos al Jetson, en vez de una RGB-D "tonta" que le pasa todo
  el cómputo crudo al Jetson. Modelo exacto pendiente de la lista de compra.
- Se comprobaron dos cámaras que el usuario ya tenía (Tapo C411, Tapo C230)
  y una Insta360 Ace Pro 2 — ninguna sirve: sin sensor de profundidad
  ninguna de las tres, y además la Tapo depende de wifi/nube propietaria y
  la Ace Pro 2 es una cámara de acción sin salida de vídeo en vivo de baja
  latencia. Hace falta comprar una cámara nueva.

## Mano: adaptativa de cuatro motores (26 sept 2026)

La mano tiene que coger como una humana: un boli con **pulgar e índice**, una
pelota pequeña, un vaso, y en general cualquier objeto dentro de su límite
de carga (300-500 g).

- **Un motor rígido para toda la mano no sirve**: solo tiene una postura
  cerrada, válida para un único tamaño de objeto.
- **Tres motores** (cuatro dedos juntos + flexión y rotación del pulgar)
  coge vaso y pelota, pero el boli lo tomaría con pulgar, índice y corazón a
  la vez: es la pinza de *escribir*, no la de *coger* un objeto pequeño.
- **Cuatro motores**, que es lo elegido:

  | Motor | Mueve |
  |---|---|
  | Índice | sus 4 articulaciones |
  | Corazón + anular + meñique | juntos |
  | Flexión del pulgar | sus 3 articulaciones de flexión |
  | Rotación del pulgar | el cardán de la base: lo pone enfrente o al lado del índice |

  El índice independiente permite además **señalar**, que en un robot
  asistente que conversa con personas es comunicación, no un extra.

**Adaptativa** quiere decir que cada motor tira de tendones que recorren los
dedos, con muelles de retorno: si un dedo toca el objeto se detiene y los
demás siguen cerrando hasta tocar también. Así un mismo motor se amolda a un
vaso o a una pelota sin programar cada agarre. Los motores irían en el
antebrazo, no en la palma, para que la mano pese poco (es la solución del
humanoide de código abierto InMoov, impreso en 3D).

**Qué queda sin decidir, a propósito:** los motores concretos (modelo, par,
peso) son componente de fase 2 y siguen pendientes. Con su peso se podrán
dimensionar por fin los servos de hombro y codo, que esperaban a saber
cuánto pesa la mano.

**Consecuencias en el CAD:**

- El modelo ya tenía las 20 articulaciones repartibles en esos cuatro grupos,
  incluida la rotación del pulgar (el cardán). No hacen falta articulaciones
  nuevas.
- Faltan piezas que el diseño no tiene todavía: canales de tendón dentro de
  las falanges, anclajes y muelles de retorno.
- **El ensayo de colisiones cambia.** Hasta la v6 se cerraban los cinco dedos
  a la vez hasta el final, y el análisis mostró que 55 de los 58 choques que
  quedaban estaban en ese tramo final, el 87% del volumen pulgar contra las
  puntas de índice y corazón. Ninguna mano con pulgar oponible puede cerrar
  así sin que el pulgar acabe dentro de los dedos: por eso recortar material
  no convergía, y cada intento acababa partiendo una pieza. La v7 prueba en su
  lugar cada motor por separado (criterio: cero choques) y la pinza del boli.
  Detalle en `work/Toreto_Prueba_Holguras_01_44/`.

**Cómo debe tocar la pinza del boli (26 sept 2026, tras verla en 3D):** el
**pulgar** debe apoyar con la **cara plana de su última falange**, no con la
punta curva: la curva deja poca superficie y el boli gira o resbala. Hoy
(v8) toca de punta, contra la cara interior de la última falange del
índice. **El índice está bien así** y no se cambia. Además, las caras de
agarre serán **rugosas o con textura** para mejorar la sujeción. Cambiar la
postura del pulgar exige un ensayo nuevo; no se ha tocado todavía.

**Pinza del boli aceptada (27 sept 2026): pinza lateral.** Ensayo v10b con
sólidos: cardán girado del todo, índice y flexión del pulgar cerrando 1:0,26,
sin tocar geometría ni relaciones. Primer contacto con el índice al 78% y el
pulgar al 20%, sin ningún choque antes. El pulgar apoya con su **cara plana
palmar** (centro de la falange); el índice pone la **esquina redondeada de
su punta** (costado/cara interior), y entre ambos queda una V de unos
20-30°. Vista en 3D y aceptada por el usuario tal cual. Las yemas blandas y
rugosas ayudarán a rellenar la V. Apoyo plano contra plano descartado por
ahora: con los ejes actuales del pulgar siempre queda desalineación.

## Brazo: codo de un solo eje con pieza de enlace (27 sept 2026)

El codo tiene **un único eje de giro**, en el centro de una pieza negra de
enlace. Esa pieza va fijada a la carcasa del brazo y a la del antebrazo (los
dos círculos pequeños de la lámina son sus fijaciones, no dos ejes) y las
separa para que no choquen al doblar. Lo aclaró el usuario sobre el render
de referencia.

Medición del brazo sobre la lámina frente al brazo de prueba (el de
`work/Toreto_Prueba_Holguras_01_44/`): el codo coincide (5 mm), pero el
hombro está 67 mm desplazado y la muñeca 93 mm, porque el generador toma
longitudes y postura de la vista frontal. Detalle y cotas en
`work/Toreto_Prueba_Holguras_01_44/medicion_brazo/MEDICION_BRAZO_LAMINA.md`.

## Identidad visual: CAD 3D interactivo (23 ago 2026)

Estándar de documentación técnica para todo el material visual del proyecto:

- Visores 3D interactivos en Three.js (materiales PBR, `OrbitControls`,
  iluminación de estudio de 3 puntos, sombras dinámicas) en vez de dibujos
  estáticos.
- Láminas en layout Bento Grid, modo oscuro.
- Vistas 2D solo como proyecciones ortogonales normalizadas (con cotas y
  líneas de centros) — no como icono decorativo.

Estándar fijado en las skills `toreto-cad-visual-identity` y
`toreto-mechanical-tokens` (`.claude/skills/`). Esta última es explícita en
no inventar datos: remite a `docs/CINEMATICA.md` y a este archivo como única
fuente de verdad, y dejar como `TBD` lo que dependa de componentes aún no
elegidos (fase 2).

La primera lámina 3D bajo este estándar es un **proxy geométrico** basado en
las cotas ya conocidas (altura 950 mm, base ⌀400 mm, torso_h 228 mm, waist_h
202 mm) — no es el modelo real de Fusion, que llega en fase 3.

## Base: 4 ruedas mecanum (23 ago 2026)

La base móvil usa **4 ruedas mecanum en disposición rectangular**, holonómica
(traslación en cualquier dirección y giro sobre su eje sin necesidad de
orientar las ruedas). Altura (95 cm) y el resto de medidas generales no
cambian.

Actualizado: `README.md`, `docs/CINEMATICA.md` (nodos `wheel_fl/fr/rl/rr`).

**Confirmado el 29 sept 2026:** el render 3D dibuja ruedas omnidireccionales
de doble fila, pero se mantienen **mecanum** (lo que dibuja el lienzo y lo
que da movimiento lateral con las cuatro ruedas paralelas), con el
**aspecto del render**: rodillos más gruesos y juntos, tapa negra con luz.

## Brazo: requisitos de movimiento y fuerza (30 sept 2026)

- **Juntar las manos delante del pecho.** Con un solo eje en el hombro y otro
  en el codo cada brazo se mueve en su propio plano vertical (separados unos
  400 mm) y las manos nunca se acercan. Por eso el brazo lleva **hombro 2
  (subir/bajar + rotación del brazo sobre su eje) + codo 1 + muñeca 2**; con
  el codo a 90° y el brazo girado, antebrazo (164 mm) y mano (~90) llegan al
  centro. Pendiente comprobar en el modelo que al plegarlos no chocan con el
  pecho.
- **Carga: 1 kg por mano, también con el brazo estirado** (el usuario
  descartó rebajarlo a 0,5 kg estirado: "es muy poco").
- **Coste:** los actuadores comerciales (2.000-4.000 € los dos brazos) son
  demasiado caros. Vía elegida: **reductoras impresas en la P1S** (cicloidal
  en hombro y rotación del brazo, NEMA17 + TMC2209), servos baratos en la
  muñeca y micromotores con tendones en la mano; objetivo ~300 € los dos
  brazos. Motores del hombro dentro del pecho y el del codo cerca del
  hombro para aligerar el brazo. Primero un prototipo del hombro que
  demuestre 15 N·m; si aguanta, se repite en el resto.
- **Par mínimo por articulación** (brazo estirado en horizontal con 1 kg,
  margen ×2). Masas SUPUESTAS hasta elegir piezas: brazo con motor de codo
  0,6 kg, antebrazo con motores de muñeca y mano 0,8 kg, mano 0,25 kg;
  largos del modelo: hombro-codo 157 mm, codo-fin del antebrazo 164 mm.

  | Articulación | Par estático | Mínimo con margen |
  |---|---|---|
  | Hombro subir/bajar | ~7,2 N·m | **~15 N·m** |
  | Hombro rotación del brazo (codo a 90°) | ~3,6 N·m | ~7 N·m |
  | Codo | ~3,6 N·m | ~7 N·m |
  | Muñeca | ~0,9 N·m | ~2 N·m |

  Recalcular con las masas reales en cuanto se elijan los motores. Aligerar
  el antebrazo (motores de la mano cerca del codo) es lo que más baja el par
  del hombro. La carga adelanta el centro de masas: comprobar el equilibrio
  con el brazo estirado y 1 kg.

## Ally en el pecho, iPhone en la cabeza (1 oct 2026)

**Decidido** tras revisarlo con la maqueta `Toreto_Maqueta_Ally_Pecho`
1.2.2 (todo cabe; los choques que quedan son de cómo se dibujaron las zonas
reservadas). **Sustituye** a "Ordenador de a bordo: … bahía extraíble en la
base": la Ally ya no va en la base. **Cabeza ~15 mm más alta** (160 → 175)
para que el giro del iPhone (156 mm) no asome por los cantos. El usuario
acepta que el robot pase de 950 a **~965 mm**; el cuello no se acorta.

- **ROG Xbox Ally X en el pecho, a la vista** (pantalla táctil y mandos
  usables desde fuera, aire retro). Pecho ensanchado de 252 a 321 mm hacia
  el hueco de los discos del hombro, con un aro negro fino; los brazos no
  se mueven. Ventilación de la Ally: toma aire por los lados y lo expulsa
  por arriba (análisis de MuyComputer, 15-10-2025).
- **iPhone 12 Pro Max en la cabeza con giro tipo libro** (eje en su borde
  largo, guías en semicírculo, servo pequeño): modo cara (pantalla al
  frente, cámara TrueDepth) y modo visión (3 cámaras + LiDAR al frente, sin
  recortes de visión). Las cámaras no se pueden separar ni alargar del
  iPhone (emparejamiento de piezas y calibración de fábrica).
- Ahorro seguro ~100-170 € (pantalla de cabeza, micrófonos, altavoz); la
  OAK-D sigue prevista hasta probar el iPhone en modo visión.
- Resuelto: la cabeza (160 mm) era justa para los 156 mm del giro y los
  cantos dejaban asomar el iPhone 2-5 mm; se hace ~15 mm más alta.
- Puertos de la Ally (2 × USB4, jack) y botón de encendido con huella:
  **borde superior, a la izquierda** vista de frente. Hueco de cables
  reservado ahí (fuera del bloque del cuello). Pecho a 327 mm para dejar
  10 mm de aire a cada lado de la Ally.
- **Encendido por software, sin pulsador mecánico** (podría pulsar o
  dañar el botón con las vibraciones). La Ally queda en reposo moderno y la
  despierta el microcontrolador de seguridad haciendo de teclado USB
  (activar "permitir que este dispositivo reactive el equipo" en el
  Administrador de dispositivos). **Wake-on-WLAN descartado:** el reposo
  moderno no responde al paquete de despertar por red. Desde apagada solo
  serviría cortar y devolver la corriente del USB-C si la Ally arranca sola
  al recibirla (pendiente de comprobar); si no, no apagarla nunca del todo.
  Configuración: en el dispositivo HID del microcontrolador y en los
  concentradores raíz USB, permitir reactivar el equipo y NO permitir
  apagarlos para ahorrar energía; suspensión selectiva de USB desactivada
  (con `powercfg` si está oculta). El microcontrolador se alimenta de la
  batería del robot, no del USB de la Ally, para poder despertarla aunque
  el puerto quede sin corriente.

## Motores de tornillo sin fin y esqueleto de aluminio (3 oct 2026)

**Cambio de criterio en los motores grandes.** Las pruebas publicadas de
reductoras cicloidales impresas con NEMA17 dan ~3,4 N·m de par seguro y
~10,5 N·m de pico (PETG), y acaban rompiéndose si se bloquean (Hackaday,
ago 2026). No llegan a los 15 N·m del hombro ni a los ~30 (60 con margen)
de la cadera. Un NEMA23 con planetaria 50:1 comercial da ~10 N·m (~142 €).

- **Cadera y hombro subir/bajar (×2): motores de tornillo sin fin** de
  20-45 N·m (tipo limpiaparabrisas): no giran sin corriente (sin muelle ni
  freno), baratos. Driver de continua BTS7960 (43 A) y sensor AS5600 en el
  eje de salida. Limitar corriente por seguridad (no ceden si chocan).
  Mirar el par NOMINAL en la ficha antes de comprar.
- **Rotación del brazo, codo, cintura: elevalunas o motores de asiento**
  (tornillo sin fin, 5-15 N·m), o cicloidal/planetaria impresa con NEMA17.
- Muñeca y mano: servos y micromotores (sin cambios).
- **Desguace:** limpiaparabrisas delanteros (mejor de camión, 24 V) para
  cadera y hombros, iguales entre sí; elevalunas y motores de asiento para
  brazo y cintura; limpiaparabrisas trasero para cuello o cintura. Traer el
  conector con cable, probar con batería, fotos con regla.
- Descartado para la cadera: actuador lineal (no cabe y pierde par al
  final) y muelle de gas (el usuario no lo quiere junto al calor).

**Esqueleto de aluminio** (lo hace un tío del usuario que trabaja el
aluminio; pendiente de confirmar con él): placa de base 5 mm (o 4 mm con
nervios), columnas de tubo 25 × 25 × 2, pletinas de 6 mm para los soportes
de cadera y hombros y el travesaño de los hombros, eje de cadera tubo Ø30 ×
3, espinas de los brazos en pletina de 4 mm, escuadras. 6082-T6 / 6061-T6
(6063 para tubos). ~4-5 kg de aluminio, ~65-110 € + tornillería y
rodamientos ≈ 95-165 €. Se diseña en Fusion DESPUÉS de tener los motores;
luego planos acotados / DXF para él.

## Equipos de desarrollo: servidor de casa y torre (3 oct 2026)

Fuera del robot, todo en casa (sin nube):

- **Servidor 24/7 con Proxmox**, con las piezas que sobren al cambiar de PC
  (placa y procesador DDR4) + 4 × 8 GB Corsair Vengeance LPX
  CMK16GX4M2B3200C16 (32 GB; puede que haya que bajarlas a 2933-3000 MHz)
  + fuente Corsair 850 W 80 Plus Gold + SSD de 500 GB (Proxmox y VM).
  Sin gráfica (~35-55 W en reposo, ~5-7 €/mes). VM con TrueNAS u
  OpenMediaVault, VM con Ubuntu + ROS 2, contenedores. Datos en 2 discos
  NAS CMR (WD Red Plus / IronWolf) de 4 TB en espejo (~200 €); copias
  según la regla 3-2-1 (disco USB + GitHub).
- **Torre con RTX 5080 + RTX 4070 Ti** (16 + 12 GB): solo cuando haga
  falta, encendida desde el servidor por Wake-on-LAN por cable. Para lo
  pesado: modelos de IA grandes, entrenar visión, simulación (Gazebo,
  Isaac Sim).
- La IA del día a día sigue en la Ally, dentro del robot.

## Giros deseados y cadera (2 oct 2026)

Requisitos de movimiento (no límites medidos; 0° = postura de la lámina).
Los límites reales se medirán con el pecho y la cabeza definitivos.

| Articulación | Giro | Para qué |
|---|---|---|
| Cuello, a los lados | ±90° | Mirar a quien habla a su lado |
| Cuello, arriba/abajo | +30° / −45° | Cara de un adulto de pie a 1,5 m / manos y mesa |
| **Cadera, inclinar adelante** | **0° a +85° (mecánica); +30° por software al principio** | Mesas bajas, estanterías; con 80-85° recoger del suelo |
| Cintura, girar | ±150° | Girar el tronco sin mover ruedas (no 360°: cables) |
| Hombro, subir/bajar | −30° / +130° | Estantería alta, brazo algo atrás |
| Hombro, rotación del brazo | ±90° | Juntar las manos delante del pecho |
| Codo | 0° a 135° | Llevar cosas al pecho, plegar |
| Muñeca 1, girar la mano | ±90° | Pomo, verter |
| Muñeca 2, doblar la mano | ±60° | Orientar la mano |
| Volteo del iPhone | 0° / 180° | Modo cara / modo visión |

**Cadera nueva:** bisagra de izquierda a derecha donde la cintura entra en
el tronco (Z ~400). La U del collar del tronco hace de cadera (abierta
delante y detrás); el fondo del bloque inferior de la cintura se redondea en
arco alrededor del eje. Motor: **actuador lineal de 24 V** (tipo mueble,
500-1.500 N, ~20-40 €) dentro del tronco con palanca de ~8 cm: ~80 N·m, no
se cae sin corriente, lento.

**Recoger del suelo (cambiado el mismo día a petición del usuario):** con el
hombro a 290 mm sobre la cadera y brazo + mano de ~410 mm, la mano baja a
~240 mm a 30°, ~135 mm a 60°, **~40 mm a 80°** y toca el suelo a ~88°. Por
eso:
- **La cadera se diseña para 85°:** U del collar muy abierta por delante
  para que pase el fondo del bloque de la cintura, y biela de dos brazos
  para que el actuador lineal cubra 85° (~30 N·m, ~60 con margen).
- **Software la limita a 30°** hasta pesar el robot real. Estimación con
  masas supuestas: a 85° el centro de gravedad queda a ~10 cm del centro
  (ruedas delanteras a ~15 cm); con 1 kg en cada mano, ~12 cm: poco margen.
  Con los pesos reales se calcula el vuelco y, si sale bien, se habilita.
- Al recoger del suelo: robot quieto, despacio, poca carga y la IMU de la
  base vigilando la inclinación.

## Batería: LiFePO4 24 V ~384 Wh en la base, 5 h de uso (1 oct 2026)

- **Requisito del usuario: 5 horas de uso continuo** sin cargar.
- Consumo estimado (a medir con los motores reales): ~60-70 W de media
  (Ally ~20 W, iPhone ~5 W, ruedas ~10 W, brazos ~10-20 W, cuello y
  cintura ~3 W, LIDAR + OAK-D + electrónica ~8 W, pérdidas ~10 %); picos de
  ~250-300 W. La Ally (80 Wh) y el iPhone (~14 Wh) llevan su propia batería
  y siguen vivos un rato si se agota la del robot.
- **Batería: LiFePO4 de 24 V, ~15 Ah (~384 Wh)**, ~4-5 kg, con BMS. Elegida
  frente a Li-ion por seguridad en casa (no arde) y vida útil (2.000-4.000
  ciclos). 24 V es la tensión de los motores y drivers.
- **Va en la base**, libre desde que la Ally pasó al pecho: el peso abajo
  compensa la Ally en el pecho y el kilo en la mano.
- Acompañan: fusible, interruptor general y seta de emergencia que corta
  los motores; convertidor 24 V → USB-C PD 65-100 W para la Ally;
  convertidor 24 V → 5 V para el microcontrolador y el iPhone; cargador
  LiFePO4 de 24 V.
- **Carga a mano** por ahora: conector de carga en la parte trasera de la
  base, junto al interruptor general (tipo aviación GX16 o XT60, para los
  ~5 A del cargador). Comprar la batería solo tras comprobar sus medidas
  contra el hueco del chasis (~246 × 410 × 69 mm; la altura es lo justo).
- **Sitio reservado para una base de carga automática futura:** dos
  contactos de muelle en la parte trasera e inferior de la base, a
  ~40-60 mm del suelo, con su cableado previsto hasta la batería. Se añaden
  sin rehacer la base cuando la navegación sepa volver a la estación.

## Cables y calor: requisitos (1 oct 2026)

- **Bus CAN** para todos los motores: cada brazo baja a 4 hilos (24 V, GND,
  CAN-H, CAN-L) que pasan **por dentro del eje del hombro, hueco (Ø10-12)**.
- **Canal central** de ~60 × 60 mm de arriba abajo del pecho, con la
  **columna de aluminio 2020** que sube desde la base y lleva el mazo de
  cables hacia la cintura y el cuello. Nada puede ocuparlo.
- **Aire:** entrada por rejillas en los costados del pecho (≥10 mm entre la
  Ally y la pared), salida por rejillas en el techo del pecho a los lados
  del cuello; rejilla trasera en la cabeza para el iPhone; el cuello no
  debe meter en la cabeza el aire caliente del pecho.
- Calor estimado en el pecho, peor caso: ~45-55 W (Ally 35 W + motores del
  hombro). Los drivers bajan la corriente con el brazo quieto.
- **Siguientes temas:** límites de giro de cada articulación y baterías
  (Ally + iPhone + motores; primera estimación 300-500 Wh).

## Hombro: unión pecho-brazo con discos apilados (29 sept 2026)

El lienzo dibuja la unión del hombro como **discos negros apilados** y el
render como un solo cilindro. Se sigue el **lienzo**: el usuario lo prefiere
porque varios discos grandes reparten mejor el peso del brazo. Lo que sí se
toma del render y de la vista lateral de la lámina: la parte alta del brazo
es una cápsula blanca redondeada con un **disco negro grande** en la cara
exterior (hoy es un bloque con un medio disco).

## Fuente maestra de cotas: lámina de 4 vistas calibrada (26 ago 2026)

`cad-toreto/toreto_fusion_95cm/reference/lamina_maestra_4vistas.jpg` es la
fuente única para dimensionar el exterior de 95 cm — frontal, lateral
derecho, posterior y lateral izquierdo, cada uno calibrado de forma
independiente contra la silueta real del robot en esa vista (no contra una
caja de recorte), a 0,5 mm/px exactos entre Z=0 (suelo) y Z=950 mm
(coronilla).

El generador (`tools/prepare_fusion_canvases.py`) valida su propia salida:
si alguna vista no cae dentro de Z=0–950 mm con menos de 3 px de margen, el
script falla en vez de escribir un lienzo mal calibrado.

Con esta fuente ya fiable, el siguiente paso es medir sobre el lienzo
frontal (maestro) las separaciones Z reales de cada módulo, y usar esa
tabla única para corregir los add-ins de Fusion y los módulos OpenSCAD de
`toreto_exterior_95cm`, que hoy no coinciden entre sí en cómo reparten los
950 mm.

## La tabla de cotas Z no se fija todavía (26 ago 2026)

La medición sobre el lienzo frontal ya está hecha —
`tools/measure_z_boundaries.py` genera la regla de píxeles reproducible,
lectura completa en `docs/CUADERNO.md`— pero el usuario decidió **no
fijarla como tabla única todavía**: dónde caen los cortes reales de
tronco/cintura/pecho depende de dónde queden la batería y los mecanismos
internos, y eso es fase 2 (componentes), no fase 1 (silueta exterior). Fijar
la tabla solo con la silueta de fuera sería inventar una cota que luego
puede no tener sitio por dentro — exactamente lo que la regla de
[orden de trabajo](#orden-de-trabajo-diseño--componentes--cad) quiere evitar.

Los 10 add-ins de Fusion y los 5 módulos OpenSCAD siguen, por tanto, con sus
valores por defecto actuales (no coincidentes entre sí) hasta que haya
componentes elegidos y la tabla se pueda fijar con conocimiento de qué va
dentro de cada módulo.

## Documentos vivos (fuera de este repo)

Se publican como artefactos porque se consultan desde la tablet. Al
actualizarlos, republicar sobre la misma URL, no crear uno nuevo:

- [Índice del proyecto](https://claude.ai/code/artifact/3c1e9e5f-cfa8-4d47-8dd7-55fb1f6f150b)
- [Lámina de diseño](https://claude.ai/code/artifact/774ba526-7714-4aee-aeff-1aad35ca3a55)
- [Stack de herramientas](https://claude.ai/code/artifact/6abfaa55-f3db-4c18-a0bd-476af38d9d59)

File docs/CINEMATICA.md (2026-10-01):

# Árbol cinemático (planificación)

Este diagrama **no es el URDF final** — es la jerarquía de enlaces y
articulaciones que se espera montar en Fusion en la fase 3 y exportar con el
plugin URDF Exporter. Los tipos de joint son los previstos; los ángulos límite
y el actuador de cada uno quedan como `TBD` hasta cerrar la fase 2
([`ROADMAP.md`](ROADMAP.md), milestone v0.2).

Las clases de color (`estructura`/`actuador`/`sensor`) y el estándar de
visualización técnica del proyecto (visores 3D, láminas Bento Grid, vistas
ortogonales normalizadas) los fijan las skills
[`toreto-cad-visual-identity`](../.claude/skills/toreto-cad-visual-identity/SKILL.md)
y [`toreto-mechanical-tokens`](../.claude/skills/toreto-mechanical-tokens/SKILL.md)
— no son arbitrarios, para que cualquier pieza nueva del proyecto use la misma
clave visual sin tener que redecidirla cada vez.

Sirve para razonar la estructura ahora, sin bloquear nada de CAD ni de
componentes — y como referencia directa cuando llegue el momento de nombrar
los links y joints reales en Fusion, para que coincidan con este árbol.

```mermaid
graph TD
    classDef estructura fill:#eef2f4,stroke:#5d7284,color:#152430
    classDef actuador fill:#0e86b8,stroke:#0e86b8,color:#ffffff
    classDef sensor fill:#1a7f5a,stroke:#1a7f5a,color:#ffffff

    base[["base_link<br/>base móvil"]]:::estructura
    w1((wheel_fl)):::actuador
    w2((wheel_fr)):::actuador
    w3((wheel_rl)):::actuador
    w4((wheel_rr)):::actuador
    lidar([lidar_link]):::sensor

    base -->|"continuous · TBD"| w1
    base -->|"continuous · TBD"| w2
    base -->|"continuous · TBD"| w3
    base -->|"continuous · TBD"| w4
    base -->|fixed| lidar

    trunk[trunk_link<br/>tronco]:::estructura
    hip[hip_link<br/>cintura inferior]:::actuador
    waist[waist_link<br/>cintura superior]:::actuador
    torso[torso_link<br/>pecho + Ally]:::estructura
    base -->|fixed| trunk
    trunk -->|"revolute cadera · 0/+85° (software 30°) · actuador lineal 24 V"| hip
    hip -->|"revolute giro cintura · ±150° · TBD"| waist
    waist -->|fixed| torso

    neck_pan[neck_pan_link]:::actuador
    head[head_link]:::estructura
    phone[iphone_link]:::actuador
    camera([camera_link]):::sensor
    torso -->|"revolute pan · ±90° · TBD actuador"| neck_pan
    neck_pan -->|"revolute tilt · +30/-45° · TBD actuador"| head
    head -->|"revolute volteo iPhone · 0/180° · servo"| phone
    phone -->|fixed| camera
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

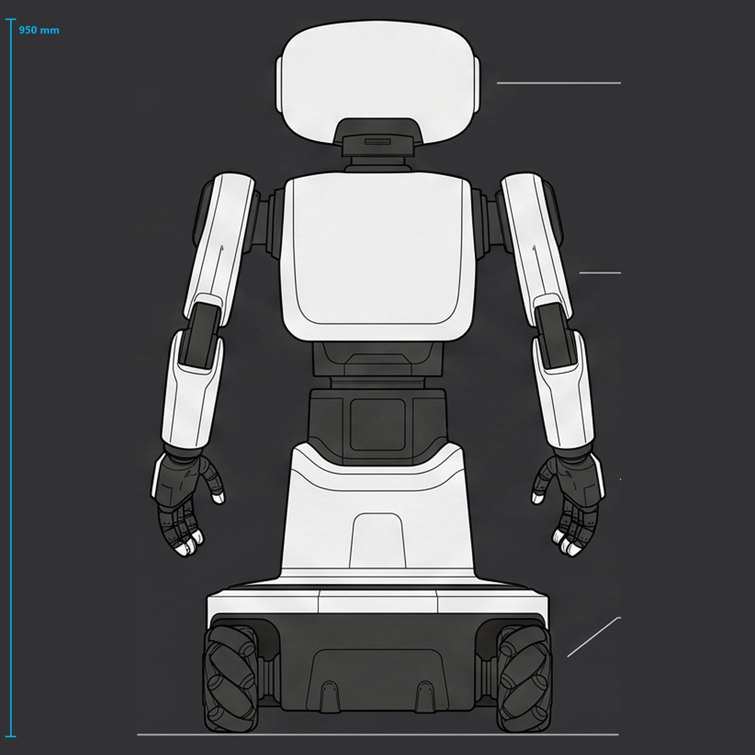
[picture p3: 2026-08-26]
cad-toreto/toreto_fusion_95cm/reference/lienzos_95cm/toreto_95cm_posterior.png

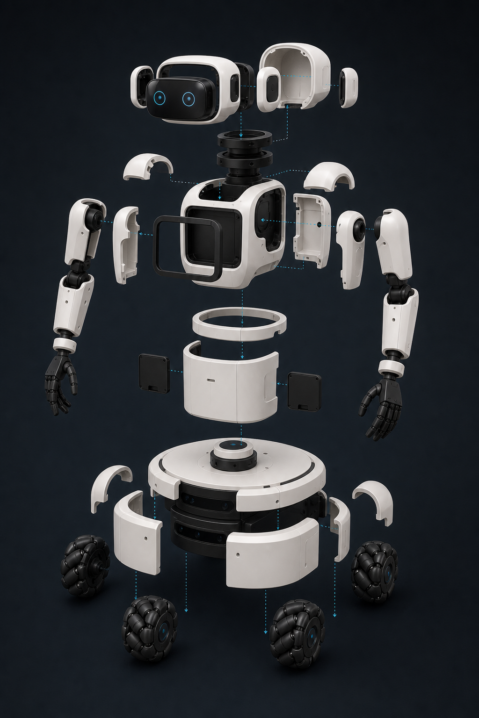
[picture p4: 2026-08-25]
cad-toreto/toreto_fusion_95cm/reference/concepto_despiece_exterior.png

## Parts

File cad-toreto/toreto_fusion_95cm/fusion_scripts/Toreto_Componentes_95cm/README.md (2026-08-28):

# Toreto_Componentes_95cm

Estructura paramétrica del ensamblaje exterior de 95 cm. Crea los componentes y planos que falten sin tocar la posición de piezas ya generadas. Solo normaliza ocurrencias nuevas y vacías; por tanto se puede volver a ejecutar sin devolver módulos a `Z=0`.

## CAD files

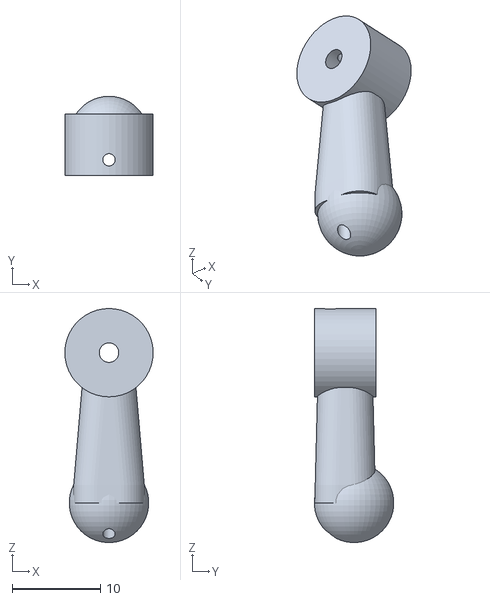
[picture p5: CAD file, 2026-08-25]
cad-toreto/toreto_exterior_95cm/exports/arms/finger_distal_main.stl
10.0 x 8.99 x 26.5

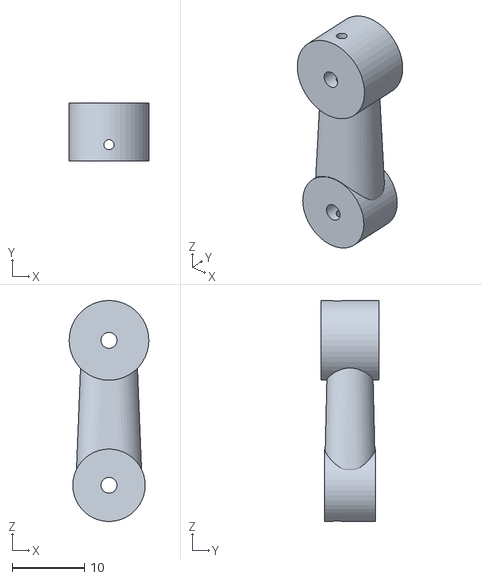
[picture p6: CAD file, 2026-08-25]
cad-toreto/toreto_exterior_95cm/exports/arms/finger_middle_main.stl
11.0 x 8.00 x 30.5

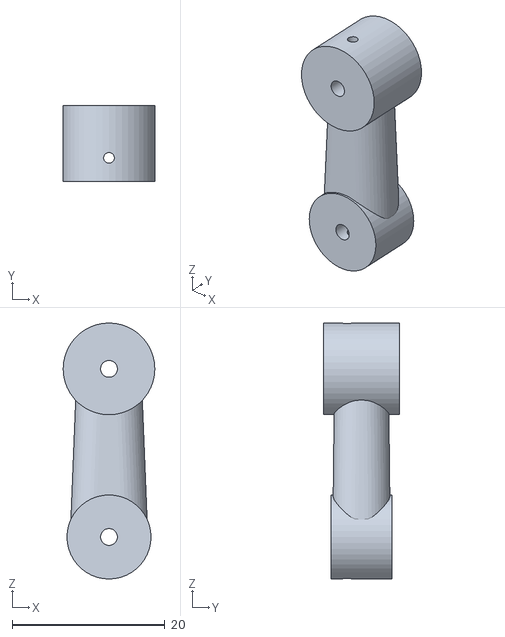
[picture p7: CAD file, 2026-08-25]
cad-toreto/toreto_exterior_95cm/exports/arms/finger_proximal_main.stl
12.0 x 10.0 x 33.5

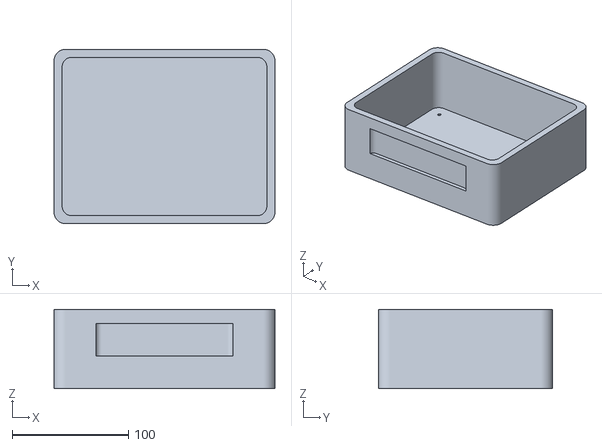
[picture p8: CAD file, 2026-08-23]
cad-toreto/exports/electronics_box.stl
190.0 x 150.0 x 68.0

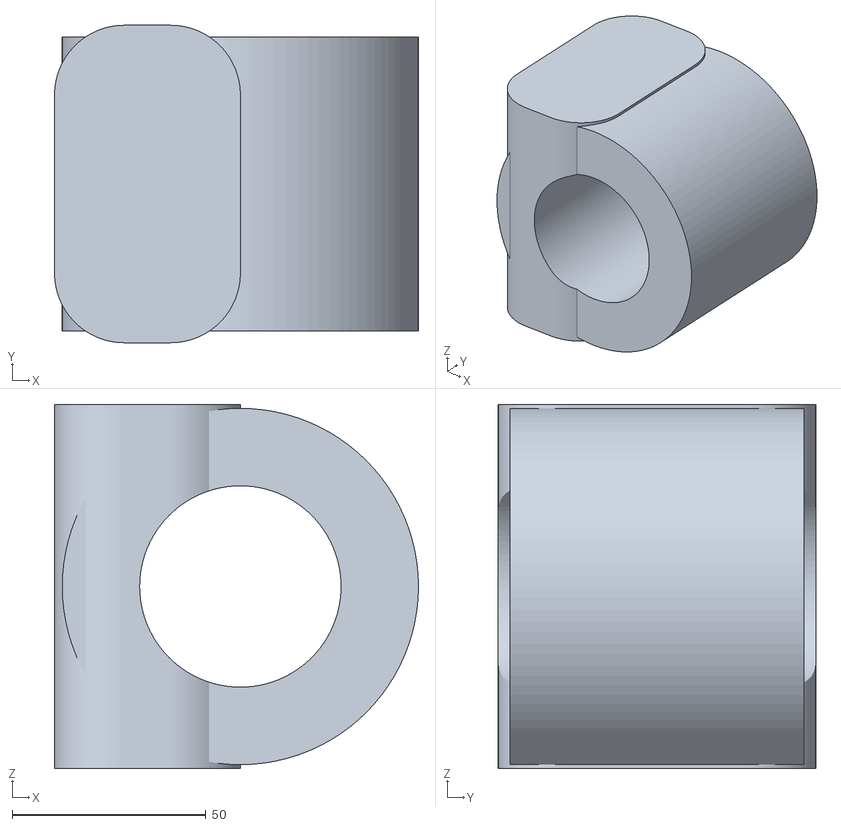
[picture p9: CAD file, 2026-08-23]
cad-toreto/exports_v2/shoulder_pod_left.stl
94.0 x 82.0 x 94.0

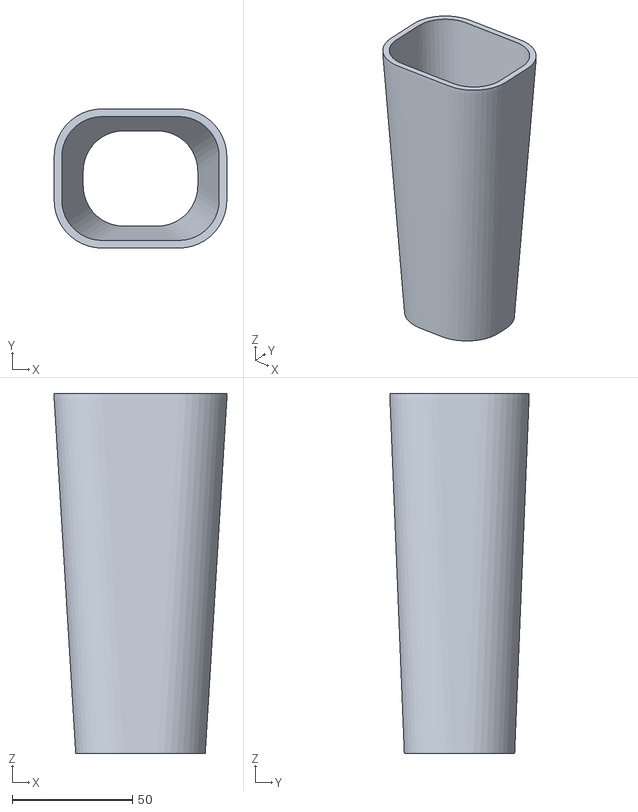
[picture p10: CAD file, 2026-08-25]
cad-toreto/toreto_exterior_95cm/exports/arms/forearm_shell_right.stl
72.0 x 58.0 x 150.0

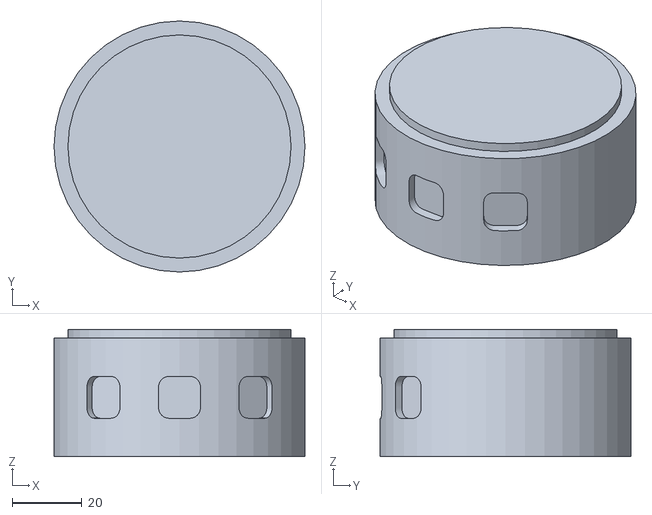
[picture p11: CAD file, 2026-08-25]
cad-toreto/toreto_exterior_95cm/exports/base/top_sensor_cover.stl
72.0 x 72.0 x 36.5

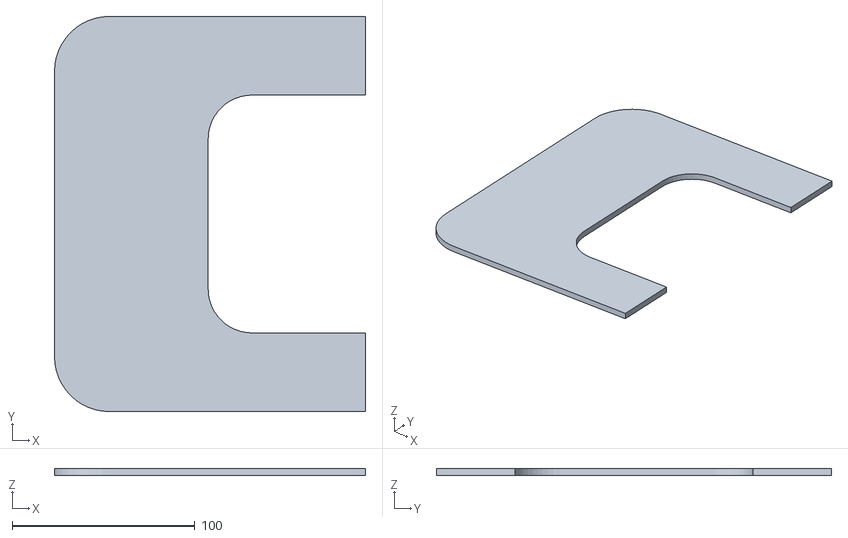
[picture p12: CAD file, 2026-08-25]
cad-toreto/toreto_exterior_95cm/exports/chest_shoulders/chest_top_left.stl
170.0 x 216.0 x 4.00

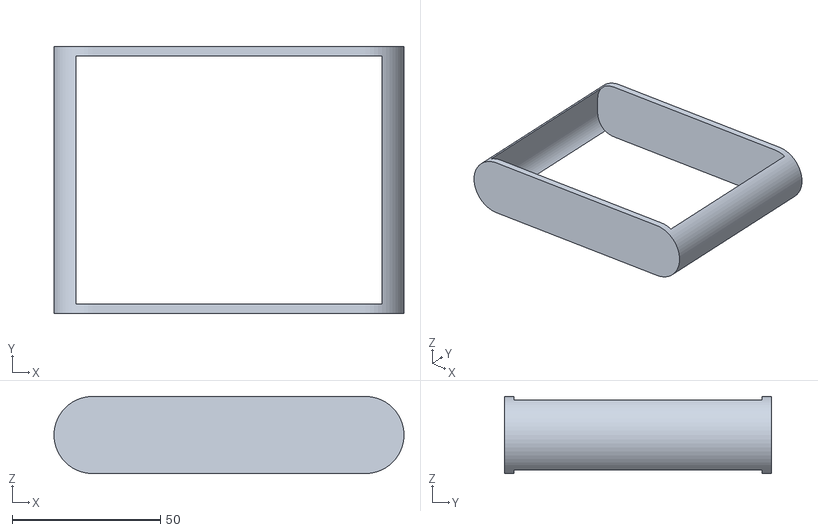
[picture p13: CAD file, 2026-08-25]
cad-toreto/toreto_exterior_95cm/exports/head_neck/neck_bridge_cover.stl
118.0 x 90.0 x 26.0

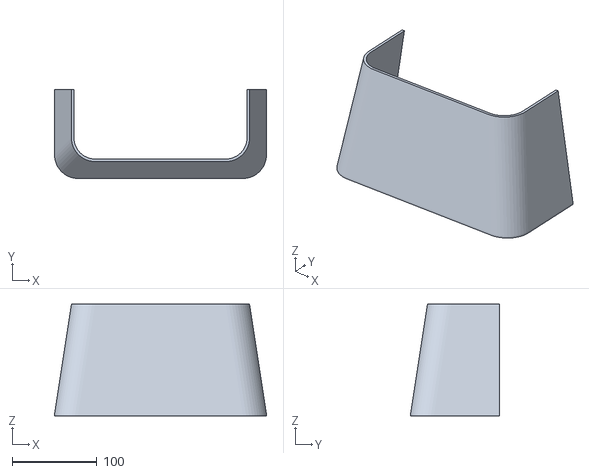
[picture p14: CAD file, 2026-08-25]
cad-toreto/toreto_exterior_95cm/exports/trunk/lower_skirt_front.stl
250.0 x 105.0 x 132.0

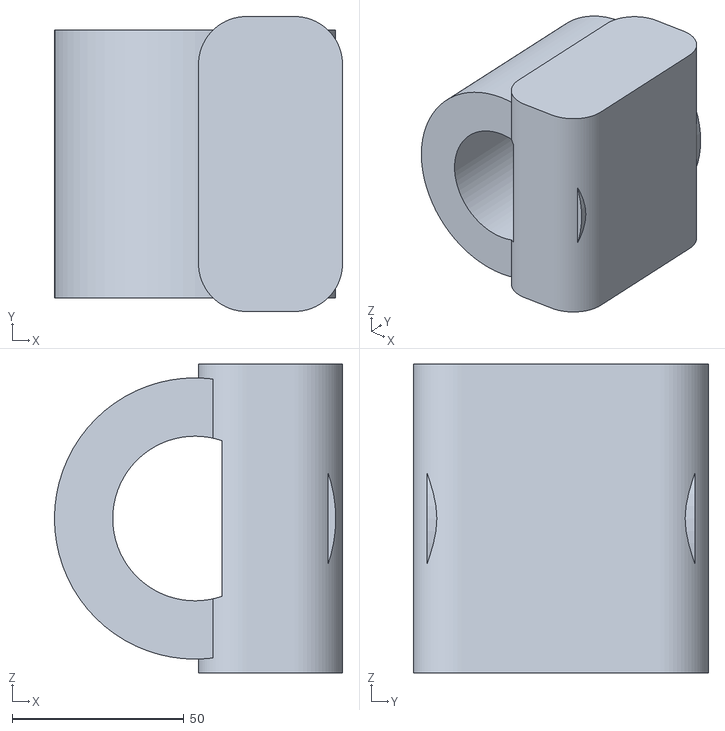
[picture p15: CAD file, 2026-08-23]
cad-toreto/exports/shoulder_mount_right.stl
84.0 x 86.0 x 90.0

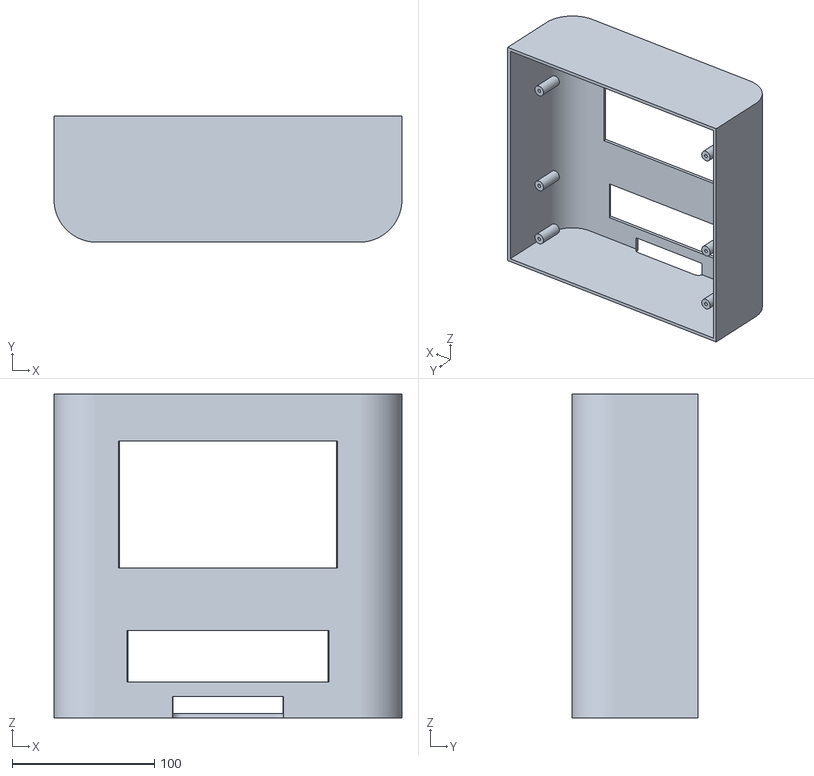
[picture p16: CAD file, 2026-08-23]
cad-toreto/exports_v2/torso_front_shell.stl
245.0 x 89.0 x 228.0

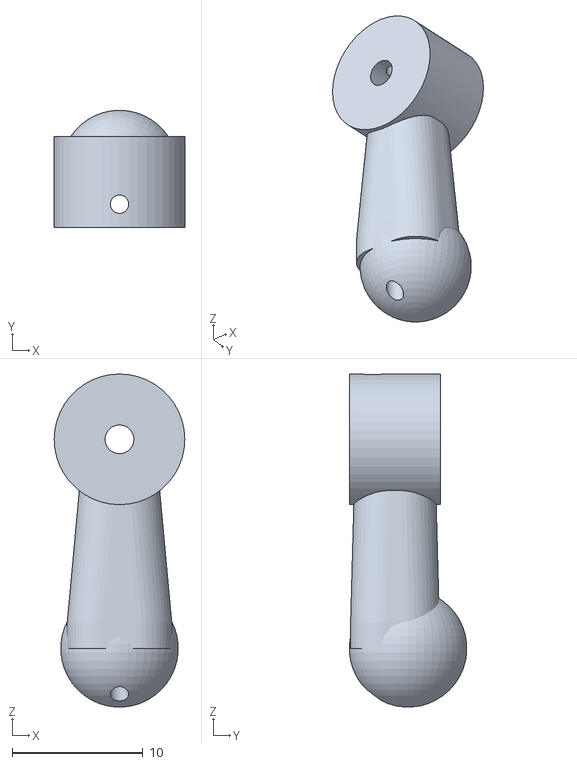
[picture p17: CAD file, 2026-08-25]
cad-toreto/toreto_exterior_95cm/exports/arms/thumb_distal.stl
10.0 x 8.99 x 25.5

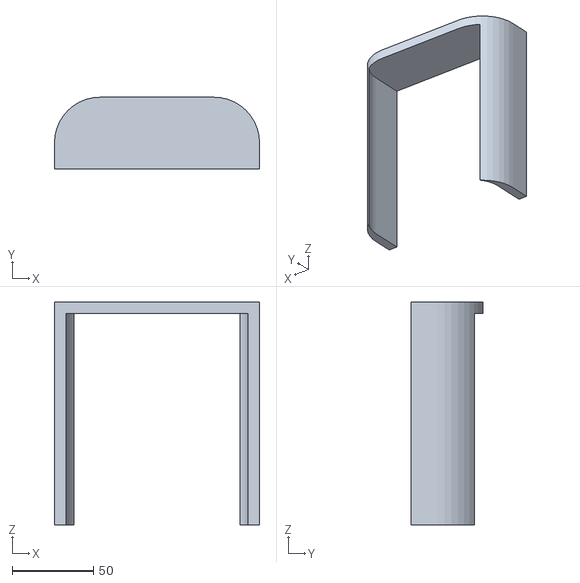
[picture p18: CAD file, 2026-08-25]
cad-toreto/toreto_exterior_95cm/exports/base/wheel_arch_shell.stl
126.0 x 44.0 x 137.0

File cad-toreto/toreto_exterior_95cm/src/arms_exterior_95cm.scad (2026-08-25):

// Robot Toreto 95 cm - módulo 5: brazos exteriores
// Basado en el quinto recorte de referencia del usuario.
// Piezas exteriores y módulos de mano preparados para articulación subactuada:
// canales y alojamientos incluidos, sin servos ni esqueleto interno.
// Unidades: milímetros.

$fn = 44;
part = "assembly";
detail_view = (part == "hand_detail");

upper_len = 170;
forearm_len = 150;
wall = 3.2;
finger_pin_d = 2.2;       // holgura para pasador/tornillo M2
finger_cable_d = 1.4;     // canal para Dyneema/Kevlar de tracción
return_pocket_d = 3.2;    // alojamiento superficial para muelle/elastómero
finger_clearance = 0.4;   // holgura lateral por lado
main_prox_len = 22;
main_mid_len = 20;
main_dist_len = 17;
thumb_prox_len = 20;
thumb_mid_len = 17;
thumb_dist_len = 16;
shoulder_pin_d = 4.4;     // paso para eje/tornillo M4

white = [0.92,0.94,0.95];
black = [0.025,0.032,0.040];
dark  = [0.065,0.075,0.085];

echo("UPPER_ARM_LENGTH_MM",upper_len);
echo("FOREARM_LENGTH_MM",forearm_len);
echo("HAND_FUNCTION","four_three_link_fingers_plus_opposed_thumb_anthropomorphic");
echo("FINGER_PIN_CLEARANCE_MM",finger_pin_d);
echo("TENDON_CHANNEL_MM",finger_cable_d);
echo("RETURN_POCKET_MM",return_pocket_d);
echo("SHOULDER_PIN_CLEARANCE_MM",shoulder_pin_d);
echo("SCOPE","external_shells_with_passive_hand_joints_no_actuators");

module rr2d(size=[20,20],r=3) {
    w=size[0]; d=size[1];
    hull()
        for (x=[-1,1],y=[-1,1])
            translate([x*(w/2-r),y*(d/2-r)]) circle(r=r);
}

module rounded_prism(size=[20,20,20],r=3,center=true) {
    translate([0,0,center ? -size[2]/2 : 0])
        linear_extrude(height=size[2]) rr2d([size[0],size[1]],r);
}

module lofted_solid(h=100,bottom=[60,50],top=[80,65],r=18) {
    hull() {
        translate([0,0,-h/2+1]) rounded_prism([bottom[0],bottom[1],2],r,true);
        translate([0,0, h/2-1]) rounded_prism([top[0],top[1],2],r,true);
    }
}

module lofted_shell(h=100,bottom=[60,50],top=[80,65],r=18,t=wall) {
    difference() {
        lofted_solid(h,bottom,top,r);
        lofted_solid(
            h+2,
            [bottom[0]-2*t,bottom[1]-2*t],
            [top[0]-2*t,top[1]-2*t],
            max(1,r-t)
        );
    }
}

module rounded_shell(size=[70,55,45],r=14,t=wall) {
    difference() {
        rounded_prism(size,r,true);
        rounded_prism([size[0]-2*t,size[1]-2*t,size[2]+2],max(1,r-t),true);
    }
}

module upper_arm_shell() {
    lofted_shell(upper_len,[60,50],[88,70],23,wall);
}

module upper_arm_seam() {
    difference() {
        rotate([90,0,0]) rounded_prism([42,76,2.4],9,true);
        translate([0,-1,0]) rotate([90,0,0]) rounded_prism([38,72,4],7,true);
    }
}

module elbow_cover() {
    rounded_shell([64,54,42],14,wall);
}

module elbow_side_cap() {
    rotate([0,90,0])
        difference() {
            cylinder(h=5,d=42,center=true);
            cylinder(h=7,d=12,center=true);
        }
}

module forearm_shell() {
    lofted_shell(forearm_len,[54,46],[72,58],20,wall);
}

module forearm_seam() {
    difference() {
        rotate([90,0,0]) rounded_prism([38,62,2.4],8,true);
        translate([0,-1,0]) rotate([90,0,0]) rounded_prism([34,58,4],6,true);
    }
}

module wrist_cuff() {
    difference() {
        lofted_solid(34,[54,46],[60,52],17);
        lofted_solid(36,[47.6,39.6],[53.6,45.6],13.8);
    }
}

// Anclaje exterior del brazo al hombro. El disco apoya sobre la tapa de
// 72 mm del pecho y el paso M4 permite una rotación pasiva. La lengüeta
// inferior entra visualmente en la carcasa abierta del brazo superior.
module shoulder_anchor() {
    difference() {
        union() {
            rotate([0,90,0]) cylinder(h=21,d=72,center=true);
            hull() {
                translate([0,0,-22]) rounded_prism([24,38,24],8,true);
                translate([-5,0,-42]) rounded_prism([28,36,26],8,true);
            }
        }
        rotate([0,90,0]) cylinder(h=40,d=shoulder_pin_d,center=true);
    }
}

// Cubierta blanca gruesa que abraza el disco negro y se solapa con la boca
// del brazo superior, igual que el hombro mostrado en la referencia.
module shoulder_outer_hood() {
    rotate([0,90,0])
        difference() {
            cylinder(h=30,d=100,center=true);
            cylinder(h=34,d=74,center=true);
        }
}

// Oreja de la palma. Dos orejas forman una horquilla y dejan libre el
// alojamiento de la falange proximal.
module palm_knuckle_ear(x=0,y=0,z=-28,ear_t=3.4) {
    hull() {
        translate([x,y,z])
            rotate([90,0,0]) cylinder(h=ear_t,d=17,center=true);
        translate([x,y,-20]) rounded_prism([17,ear_t,14],4,true);
    }
}

// Variante con eje transversal X para que los dos dedos delanteros y el
// pulgar se cierren uno contra otro, como en la referencia.
module palm_knuckle_ear_x(x=0,y=0,z=-12,ear_t=3.2) {
    hull() {
        translate([x,y,z])
            rotate([0,90,0]) cylinder(h=ear_t,d=13,center=true);
        translate([x,y,-5]) rounded_prism([ear_t,13,10],1.4,true);
    }
}

module palm_wedge_solid(h=24,top=[30,25],bottom=[34,28],r=6) {
    hull() {
        translate([0,0,h/2-1]) rounded_prism([top[0],top[1],2],r,true);
        translate([0,0,-h/2+1]) rounded_prism([bottom[0],bottom[1],2],r-1,true);
    }
}

module palm_wedge_shell() {
    difference() {
        palm_wedge_solid(24,[46,30],[54,34],7);
        palm_wedge_solid(26,[39.6,23.6],[47.6,27.6],4.8);
    }
}

// Palma antropomórfica con cuatro horquillas delanteras y un pulgar lateral.
module hand_palm_shell() {
    inner_gap = 12 + 2*finger_clearance;
    ear_t = 3.2;
    ear_x = inner_gap/2 + ear_t/2;
    front_y = -6;
    thumb_y = 7;
    pivot_z = -10;

    difference() {
        union() {
            translate([0,0,7]) palm_wedge_shell();
            translate([0,0,18]) rounded_shell([46,30,8],7,2.6);

            // Cuatro dedos delanteros, como una mano humana.
            for (cx=[-18,-6,6,18], dx=[-ear_x,ear_x])
                palm_knuckle_ear_x(cx+dx,front_y,pivot_z,ear_t);

            // Pulgar lateral opuesto, fuera del bloque de cuatro dedos.
            for (dx=[-ear_x,ear_x])
                palm_knuckle_ear_x(28+dx,thumb_y,pivot_z+3,ear_t);
        }

        for (cx=[-18,-6,6,18])
            translate([cx,front_y,pivot_z])
                rotate([0,90,0]) cylinder(h=30,d=finger_pin_d,center=true);
        translate([28,thumb_y,pivot_z+3])
            rotate([0,90,0]) cylinder(h=30,d=finger_pin_d,center=true);
        // Guías de tendón alineadas con cada dedo.
        for (cx=[-18,-6,6,18])
            translate([cx,front_y,-2]) cylinder(h=32,d=finger_cable_d,center=true);
        translate([28,thumb_y,-1]) cylinder(h=30,d=finger_cable_d,center=true);
    }
}

// Falange modular visualmente limpia: cuerpo afilado, casquillos circulares
// y dos pasos M2 para que las tres piezas se reconozcan al primer vistazo.
module finger_link(
    len=main_prox_len,
    body_w=12,
    body_d=9,
    top_eye_depth=12,
    next_eye_depth=9
) {
    difference() {
        union() {
            translate([0,0,-len/2])
                lofted_solid(len,[body_w,body_d],[body_w*0.84,body_d*0.84],max(2,body_w/3));
            rotate([90,0,0]) cylinder(h=top_eye_depth,d=body_w+2,center=true);
            translate([0,0,-len])
                rotate([90,0,0])
                    cylinder(h=next_eye_depth,d=body_w+1,center=true);
        }
        // Canal longitudinal para el tendón de cierre.
        translate([0,-body_d/4,-len/2])
            cylinder(h=len+18,d=finger_cable_d,center=true);
        // Alojamiento dorsal superficial para muelle de torsión o elastómero.
        translate([0,body_d/2-0.9,-len+2])
            rotate([90,0,0]) cylinder(h=2.0,d=return_pocket_d,center=true);
        translate([0,0,0])
            rotate([90,0,0]) cylinder(h=30,d=finger_pin_d,center=true);
        translate([0,0,-len])
            rotate([90,0,0]) cylinder(h=30,d=finger_pin_d,center=true);
    }
}

// Falange distal universal con ojo central y punta redondeada.
module finger_distal(len=main_dist_len,body_w=10,body_d=8,eye_depth=8) {
    difference() {
        union() {
            translate([0,0,-len/2])
                lofted_solid(len,[body_w,body_d],[body_w*0.68,body_d*0.68],max(2,body_w/3));
            rotate([90,0,0]) cylinder(h=eye_depth,d=body_w+2,center=true);
            translate([0,1,-len]) sphere(d=body_w+1);
        }
        translate([0,-body_d/4,-len/2])
            cylinder(h=len+12,d=finger_cable_d,center=true);
        translate([0,body_d/2-0.8,-len+2])
            rotate([90,0,0]) cylinder(h=1.8,d=return_pocket_d,center=true);
        rotate([90,0,0]) cylinder(h=24,d=finger_pin_d,center=true);
    }
}
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

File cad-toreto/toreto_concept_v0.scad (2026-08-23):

// Toreto Concept V0
// Parametric CAD concept for a modular assistant robot.
// Units: millimeters.
//
// Open in OpenSCAD. Change "part" to export individual STL files.
// Suggested export parts:
// assembly, base_quadrant, base_center_plate, torso_front, torso_back,
// head_front, head_back, head_side_pod, upper_arm_shell, forearm_shell,
// wrist_gripper_concept, wheel_cover, sensor_panel.

$fn = 72;

part = "assembly";
show_exploded = true;

// Printer envelope for Bambu P1S reference.
printer_x = 256;
printer_y = 256;
printer_z = 256;

// Main robot reference dimensions.
target_height = 950;
base_diameter = 400;
base_height = 150;
torso_w = 230;
torso_d = 170;
torso_h = 220;
neck_h = 78;
head_w = 220;
head_d = 120;
head_h = 112;
wall = 3.0;
fit_clearance = 0.35;

// ---------- Utility geometry ----------

module rounded_rect_2d(size=[20, 20], r=3) {
    hull() {
        translate([r, r]) circle(r=r);
        translate([size[0]-r, r]) circle(r=r);
        translate([r, size[1]-r]) circle(r=r);
        translate([size[0]-r, size[1]-r]) circle(r=r);
    }
}

module rounded_box(size=[20, 20, 20], r=3, center=true) {
    translate(center ? [-size[0]/2, -size[1]/2, -size[2]/2] : [0, 0, 0])
        linear_extrude(height=size[2])
            rounded_rect_2d([size[0], size[1]], min(r, min(size[0], size[1]) / 2 - 0.1));
}

module half_space(side="front", size=[1000, 1000, 1000]) {
    // Front is negative Y. Back is positive Y.
    if (side == "front") {
        translate([0, -size[1]/4, 0]) cube([size[0], size[1]/2, size[2]], center=true);
    } else {
        translate([0, size[1]/4, 0]) cube([size[0], size[1]/2, size[2]], center=true);
    }
}

module screw_boss(h=12, od=9, id=3.1) {
    difference() {
        cylinder(h=h, d=od, center=true);
        cylinder(h=h+0.4, d=id, center=true);
    }
}

module m3_hole(h=20) {
    cylinder(h=h, d=3.2, center=true);
}

module m4_hole(h=20) {
    cylinder(h=h, d=4.3, center=true);
}

module mirror_x(enabled=false) {
    if (enabled) mirror([1, 0, 0]) children();
    else children();
}

module label_plate(size=[38, 12, 1.6]) {
    color([0.02, 0.02, 0.02])
        rounded_box(size, r=2, center=true);
}

// ---------- Head ----------

module head_outer() {
    rounded_box([head_w, head_d, head_h], r=20, center=true);
}

module head_inner() {
    rounded_box([head_w - 2*wall, head_d - 2*wall, head_h - 2*wall], r=17, center=true);
}

module head_shell(side="front") {
    difference() {
        intersection() {
            difference() {
                head_outer();
                head_inner();
            }
            half_space(side, [320, 240, 180]);
        }

        // Split seam clearance.
        if (side == "front") {
            translate([0, 0.25, 0]) cube([260, fit_clearance, 140], center=true);
        } else {
            translate([0, -0.25, 0]) cube([260, fit_clearance, 140], center=true);
        }

        // Face screen opening and camera/microphone holes.
        if (side == "front") {
            translate([0, -head_d/2 - 0.2, 8])
                rounded_box([166, 12, 64], r=10, center=true);

            for (x=[-48, 48]) {
                translate([x, -head_d/2 - 3, 18])
                    rotate([90, 0, 0])
                        cylinder(h=20, d=20, center=true);
            }

            for (x=[-76, 76]) {
                translate([x, -head_d/2 - 3, -25])
                    rotate([90, 0, 0])
                        cylinder(h=20, d=5, center=true);
            }
        }
    }

    // Internal screw bosses for joining both halves.
    for (x=[-88, 88], z=[-38, 42]) {
        translate([x, side == "front" ? -18 : 18, z])
            rotate([90, 0, 0])
                screw_boss(h=18, od=9, id=3.1);
    }
}

module head_side_pod(left=true) {
    mirror_x(!left)
        difference() {
            union() {
                translate([head_w/2 + 14, 0, 0])
                    rotate([90, 0, 0])
                        cylinder(h=46, d=72, center=true);
                translate([head_w/2 + 8, 0, 0])
                    rounded_box([28, 56, 76], r=12, center=true);
            }
            translate([head_w/2 + 14, 0, 0])
                rotate([90, 0, 0])
                    cylinder(h=50, d=45, center=true);
            translate([head_w/2 + 14, -24, 0])
                rotate([90, 0, 0])
                    m4_hole(20);
            translate([head_w/2 + 14, 24, 0])
                rotate([90, 0, 0])
                    m4_hole(20);
        }
}

module head_assembly() {
    color([0.88, 0.86, 0.82]) head_shell("front");
    color([0.78, 0.77, 0.73]) head_shell("back");
    color([0.88, 0.86, 0.82]) {
        head_side_pod(true);
        head_side_pod(false);
    }
    translate([0, -head_d/2 - 5, 8]) color([0.01, 0.02, 0.03])
        rounded_box([160, 5, 58], r=9, center=true);
}

// ---------- Neck ----------

module neck_column() {
    difference() {
        union() {
            cylinder(h=neck_h, d=72, center=true);
            translate([0, 0, -neck_h/2 + 7]) cylinder(h=14, d=96, center=true);
            translate([0, 0, neck_h/2 - 7]) cylinder(h=14, d=92, center=true);
        }
        cylinder(h=neck_h + 1, d=42, center=true);
        for (a=[0:90:270]) {
            rotate([0, 0, a]) translate([34, 0, -neck_h/2 + 7]) m4_hole(18);
            rotate([0, 0, a]) translate([32, 0, neck_h/2 - 7]) m4_hole(18);
        }
    }
}

// ---------- Torso ----------

module torso_outer() {
    rounded_box([torso_w, torso_d, torso_h], r=22, center=true);
}

module torso_inner() {
    rounded_box([torso_w - 2*wall, torso_d - 2*wall, torso_h - 2*wall], r=19, center=true);
}

module torso_shell(side="front") {
    difference() {
        intersection() {
            difference() {
                torso_outer();
                torso_inner();
            }
            half_space(side, [330, 260, 300]);
        }

        if (side == "front") {
            translate([0, -torso_d/2 - 0.2, 28])
                rounded_box([116, 12, 88], r=12, center=true);
            translate([0, -torso_d/2 - 0.2, -72])
                rounded_box([150, 12, 42], r=8, center=true);
        }

        // Cable exit and service ports.
        if (side == "back") {
            translate([0, torso_d/2 + 0.2, -70])
                rounded_box([92, 12, 40], r=8, center=true);
        }
    }

    for (x=[-92, 92], z=[-86, -22, 62]) {
        translate([x, side == "front" ? -24 : 24, z])
            rotate([90, 0, 0])
                screw_boss(h=22, od=10, id=3.1);
    }
}

module shoulder_mount(left=true) {
    mirror_x(!left)
        difference() {
            union() {
                translate([torso_w/2 + 18, 0, 60])
                    rotate([90, 0, 0])
                        cylinder(h=78, d=82, center=true);
                translate([torso_w/2 - 4, 0, 60])
                    rounded_box([42, 86, 90], r=14, center=true);
            }
            translate([torso_w/2 + 18, 0, 60])
                rotate([90, 0, 0])
                    cylinder(h=82, d=48, center=true);
            translate([torso_w/2 + 18, 0, 60])
                rotate([90, 0, 0])
                    m4_hole(90);
        }
}

module torso_assembly() {
    color([0.88, 0.86, 0.82]) torso_shell("front");
    color([0.12, 0.13, 0.13]) torso_shell("back");
    color([0.12, 0.13, 0.13]) {
        shoulder_mount(true);
        shoulder_mount(false);
    }
    translate([0, -torso_d/2 - 5, 28]) label_plate([108, 5, 80]);
}

// ---------- Base ----------

module base_shell_reference() {
    difference() {
        union() {
            cylinder(h=55, d=base_diameter, center=true);
            translate([0, 0, 45]) cylinder(h=70, d=330, center=true);
            translate([0, 0, 88]) cylinder(h=24, d=245, center=true);
        }
        translate([0, 0, 10]) cylinder(h=160, d=250, center=true);
        translate([0, -base_diameter/2 + 18, 20])
            rounded_box([145, 24, 38], r=8, center=true);
    }
}

module base_quadrant() {
    // One quarter of the 400 mm base ring. Print four units.
    difference() {
        intersection() {
            cylinder(h=42, d=base_diameter, center=true);
            translate([base_diameter/4, base_diameter/4, 0])
                cube([base_diameter/2 + 2, base_diameter/2 + 2, 44], center=true);
        }
        cylinder(h=46, d=274, center=true);

        // Seam fasteners.
        for (p=[[112, 8], [178, 8], [8, 112], [8, 178]]) {
            translate([p[0], p[1], 0]) m4_hole(50);
        }

        // Pocket to reduce print time and weight.
        translate([132, 132, 0]) cylinder(h=46, d=92, center=true);
    }
}

module base_center_plate() {
    difference() {
        cylinder(h=12, d=236, center=true);
        cylinder(h=14, d=82, center=true);
        for (a=[0:45:315]) {
            rotate([0, 0, a]) translate([94, 0, 0]) m4_hole(16);
        }
    }
}
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

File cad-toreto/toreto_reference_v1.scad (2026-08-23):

// Robot Toreto Reference V1
// Visual CAD concept closer to the original reference image.
// Units: millimeters.
//
// Open in OpenSCAD. Change "part" to export individual STL files.
// This is still a concept shell: final motor, bearing, screen and battery
// holes must be adapted to the real components you buy.

$fn = 96;

part = "assembly";
exploded = false;
show_height_marker = false;

target_height = 950;

// Main proportions inspired by the reference image.
base_d = 410;
base_h = 170;
base_lower_h = 62;
base_upper_h = 74;
waist_h = 165;

torso_w = 245;
torso_d = 178;
torso_h = 265;

neck_h = 108;

head_w = 232;
head_d = 132;
head_h = 136;

wall = 3.0;
clearance = 0.35;

white = [0.88, 0.86, 0.80];
black = [0.025, 0.027, 0.027];
dark = [0.08, 0.085, 0.085];
blue = [0.00, 0.55, 0.95];
glass = [0.005, 0.010, 0.016];

// ----------------- Utilities -----------------

module rounded_rect_2d(size=[20, 20], r=4) {
    hull() {
        translate([r, r]) circle(r=r);
        translate([size[0]-r, r]) circle(r=r);
        translate([r, size[1]-r]) circle(r=r);
        translate([size[0]-r, size[1]-r]) circle(r=r);
    }
}

module rounded_box(size=[20, 20, 20], r=4, center=true) {
    translate(center ? [-size[0]/2, -size[1]/2, -size[2]/2] : [0, 0, 0])
        linear_extrude(height=size[2])
            rounded_rect_2d([size[0], size[1]], min(r, min(size[0], size[1]) / 2 - 0.1));
}

module mirror_x(enabled=false) {
    if (enabled) mirror([1, 0, 0]) children();
    else children();
}

module front_half(size=[1000, 1000, 1000]) {
    translate([0, -size[1]/4, 0]) cube([size[0], size[1]/2, size[2]], center=true);
}

module back_half(size=[1000, 1000, 1000]) {
    translate([0, size[1]/4, 0]) cube([size[0], size[1]/2, size[2]], center=true);
}

module m3_hole(h=20) {
    cylinder(h=h, d=3.25, center=true);
}

module m4_hole(h=24) {
    cylinder(h=h, d=4.35, center=true);
}

module screw_boss(h=14, od=9, id=3.25) {
    difference() {
        cylinder(h=h, d=od, center=true);
        cylinder(h=h+0.6, d=id, center=true);
    }
}

module cable_slot(size=[40, 12, 24]) {
    rounded_box(size, r=4, center=true);
}

// ----------------- Base -----------------

module base_lower_full() {
    difference() {
        union() {
            cylinder(h=base_lower_h, d=base_d, center=true);
            translate([0, -base_d/2 + 18, 5])
                rounded_box([168, 36, 34], r=10, center=true);
        }
        cylinder(h=base_lower_h+2, d=255, center=true);
        translate([0, -base_d/2 + 3, 5])
            rounded_box([128, 22, 20], r=7, center=true);
    }
}

module base_upper_full() {
    difference() {
        union() {
            cylinder(h=base_upper_h, d=360, center=true);
            translate([0, 0, 24]) cylinder(h=28, d=286, center=true);
        }
        cylinder(h=base_upper_h+35, d=176, center=true);
        for (a=[0:45:315]) {
            rotate([0, 0, a]) translate([128, 0, 0]) m4_hole(base_upper_h + 40);
        }
    }
}

module base_quadrant(level="lower") {
    h = level == "lower" ? base_lower_h : base_upper_h;
    d = level == "lower" ? base_d : 360;
    inner = level == "lower" ? 255 : 176;

    difference() {
        intersection() {
            cylinder(h=h, d=d, center=true);
            translate([d/4, d/4, 0])
                cube([d/2 + 2, d/2 + 2, h + 2], center=true);
        }
        cylinder(h=h+3, d=inner, center=true);
        for (p=[[18, 118], [18, 176], [118, 18], [176, 18]]) {
            translate([p[0], p[1], 0]) m4_hole(h+6);
        }
        translate([125, 125, 0]) cylinder(h=h+3, d=76, center=true);
    }
}

module front_sensor_panel() {
    difference() {
        rounded_box([154, 24, 38], r=8, center=true);
        for (x=[-48, 0, 48]) {
            translate([x, -13, 4])
                rotate([90, 0, 0])
                    cylinder(h=18, d=18, center=true);
        }
        for (x=[-65, 65]) {
            translate([x, -13, -12])
                rotate([90, 0, 0])
                    cylinder(h=18, d=7, center=true);
        }
    }
}

module lidar_cap() {
    difference() {
        union() {
            cylinder(h=22, d=58, center=true);
            translate([0, 0, 13]) cylinder(h=18, d=42, center=true);
        }
        translate([0, 0, 23]) cylinder(h=8, d=30, center=true);
        for (a=[0:120:240]) rotate([0, 0, a]) translate([22, 0, 0]) m3_hole(28);
    }
}

module omni_wheel_dummy() {
    // Decorative placeholder, not a functional omni wheel.
    rotate([90, 0, 0]) {
        color(black) cylinder(h=52, d=88, center=true);
        color(dark) cylinder(h=56, d=56, center=true);
    }
    for (a=[0:45:315]) {
        rotate([0, 0, a])
            translate([34, 0, 0])
                rotate([90, 0, 0])
                    color([0.11, 0.11, 0.11]) cylinder(h=58, d=14, center=true);
    }
    color(blue)
        rotate([90, 0, 0])
            cylinder(h=58, d=18, center=true);
}

module wheel_pod_shell() {
    difference() {
        rounded_box([102, 56, 92], r=16, center=true);
        rotate([90, 0, 0]) cylinder(h=64, d=76, center=true);
        translate([0, -31, 0]) rotate([90, 0, 0]) cylinder(h=10, d=84, center=true);
    }
}
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

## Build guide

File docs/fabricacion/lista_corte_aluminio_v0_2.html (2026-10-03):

# Robot Toreto – Lista de corte de aluminio (v0.2)

Versión 0.2 · 3 de octubre de 2026 · incluye todos los giros (cadera, cintura, hombros, brazos y cuello) y la base completa · Robot de ~965 mm de alto · Medidas en milímetros

Importante: son cortes en bruto (largo × ancho × espesor). Todavía no hay taladros: se marcarán en la versión 1, cuando estén elegidos los motores (de desguace o nuevos), porque los agujeros dependen de ellos. Se puede cortar ya y taladrar después.
Material: 6082-T6 o 6061-T6 en placas, pletinas y eje · 6063 vale para tubos y angulares. Se aceptan recortes siempre que salgan las medidas.

## 1. Piezas a cortar

# | Pieza | Material / perfil | Medida de corte | Uds. | Para qué | ✓

1 | Placa de la base | Chapa 5 mm | 400 × 300 × 5 | 1 | Chasis: motores de ruedas, batería y columna. (Alternativa: 4 mm + 2 angulares por debajo)
1b | Soporte de motor de rueda | Angular 50 × 50 × 4 | 60 | 4 | Uno por rueda: sujeta el motor de la rueda mecanum a la placa de la base
1c | Nervio bajo la placa | Angular 20 × 20 × 2 | 380 | 2 | Atornillados por debajo, a lo largo: la placa no flexa con el peso
1d | Tope de la batería | Angular 20 × 20 × 2 | 200 | 2 | A los lados de la batería, sobre la placa
1e | Pletina de sujeción de la batería | Pletina 3 × 25 mm | 220 | 1 | Por encima de la batería, atornillada a los topes (la batería pesa 4–5 kg)
2 | Columna fija | Tubo cuadrado 25 × 25 × 2 | 230 | 1 | De la base a la cadera
3 | Soporte de la cadera | Pletina 6 mm | 120 × 80 × 6 | 2 | Rodamientos del eje de la cadera y motor (uno a cada lado)
4 | Eje de la cadera | Tubo redondo Ø30 × 3 | 260 | 1 | Eje que gira; por dentro pasan los cables
5a | Columna de la cintura (tramo bajo) | Tubo cuadrado 25 × 25 × 2 | 70 | 1 | Del eje de la cadera al giro de la cintura (se inclina con la cadera)
5b | Columna del pecho (tramo alto) | Tubo cuadrado 25 × 25 × 2 | 270 | 1 | Del giro de la cintura al cuello (gira con la cintura)
5c | Placas del giro de la cintura | Chapa 5 mm | 130 × 130 × 5 | 2 | Una abajo y otra arriba del rodamiento de giro (Z ~465); el centro se taladrará para los cables
6 | Travesaño de los hombros | Pletina 6 mm (o tubo 40 × 20 × 2) | 300 × 60 × 6 | 1 | Une los dos motores de los hombros dentro del pecho
7 | Soporte del motor del hombro | Pletina 6 mm | 100 × 100 × 6 | 2 | Motor y rodamiento de cada hombro
7b | Soporte de la rotación del brazo | Pletina 5 mm | 90 × 70 × 5 | 2 | Motor del giro del brazo dentro de la cápsula del hombro
8 | Espina del brazo | Pletina 4 mm | 160 × 25 × 4 | 2 | Dentro de cada brazo (hombro–codo)
9 | Espina del antebrazo | Pletina 4 mm | 170 × 25 × 4 | 2 | Dentro de cada antebrazo (codo–muñeca)
9b | Placa del cuello | Chapa 5 mm | 110 × 110 × 5 | 1 | Arriba de la columna: motores del cuello (girar y arriba/abajo)
10 | Escuadra grande | Angular 30 × 30 × 3 | 40 | 8 | Uniones de columnas, placa y soportes
11 | Escuadra pequeña | Angular 20 × 20 × 2 | 30 | 8 | Fijar electrónica y piezas pequeñas

## 2. Material en barra (para pedir o buscar en recortes)

Material / perfil | Necesario (con margen de corte) | Piezas
Chapa 5 mm | 400 × 300 + recortes de ~130 × 130 (×2) y 110 × 110 | 1, 5c, 9b
Pletina 6 mm | ~0,9 m (en anchos de 60–120 mm) | 3, 6, 7
Pletina 5 mm | ~0,2 m × 90 mm | 7b
Angular 50 × 50 × 4 | ~0,3 m | 1b
Pletina 3 × 25 mm | ~0,25 m | 1e
Pletina 4 × 25 mm | ~0,7 m | 8, 9
Tubo cuadrado 25 × 25 × 2 | ~0,6 m | 2, 5a, 5b
Tubo redondo Ø30 × 3 | ~0,3 m | 4
Angular 30 × 30 × 3 | ~0,35 m | 10
Angular 20 × 20 × 2 | ~1,45 m | 1c, 1d, 11
Total aluminio | ~5,5 kg

## 3. Notas para el taller

- Cantos sin rebabas; no hace falta acabado estético (va todo dentro de carcasas impresas).
- Si sobra algún recorte de 6 mm o de tubo 25 × 25, guardarlo: saldrán más soportes.
- Los soportes de las ruedas (1b) se taladran según el motor de rueda que se elija; con motores de 37 mm (los habituales en ruedas mecanum) suele bastar el angular de 50 × 50.
- La versión 1 llevará los taladros acotados (y DXF si hay máquina de corte).

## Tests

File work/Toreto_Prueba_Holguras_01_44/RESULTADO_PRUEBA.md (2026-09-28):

# Prueba en Fusion — 2026-09-24

## v14: alturas del montaje (solo lectura) — 29-09-2026

El usuario vio huecos entre cintura y tronco y entre cuello y cabeza (Medir:
5,00 mm cada uno). `MODE='alturas'` (no cambia nada) dio en el montaje:
tronco 200-385 (hecho con alto_tronco 185; el zócalo mide exactamente esa
escala) y cuello 730-785 (hecho con alto_cuello 55); base, cintura (390-540),
pecho (540-730) y cabeza (790-950) correctos. Solapes a propósito: torreta del
LIDAR sobre la base (204-229) y discos del hombro/inserto del cuello sobre el
pecho. Arreglo preparado: Tronco 1.3.1 y Cuello 1.2.1 (misma geometría, solo
versión, para que se regeneren con los parámetros actuales), copiados a
%APPDATA%. SIN ejecutar todavía. Informe: `alturas_montaje_v14.json`.

## v13c + pecho 2.6.0: RESULTADO en el montaje — 28-09-2026 — hombro unido al pecho

Pecho 2.6.0 ejecutado en el montaje (24 cuerpos, Z 540-737,8), brazo v13c
generado (todo a 0,0 mm) y reemplazado, mano izquierda rearticulada (20 juntas,
16 relaciones, 0,001 mm). Vista frontal: la pieza negra de hombro une pecho y
brazo en los dos lados, como en la lámina. Interferencia: ninguna entre brazo
y pecho. Nuevas filas carcasa del pecho - `07_CONECTOR_HOMBRO_IZQ/DER`
(11021,5 mm3 cada una): el disco junto al pecho entra 2 mm en la carcasa a
propósito (fijación), del mismo tipo que las demás piezas del pecho embutidas.

## v13c + pecho 2.6.0: pieza de hombro como la lámina — 28-09-2026

El usuario vio en el montaje un hueco de ~40 mm entre pecho y brazo: el
conector del pecho 2.5.0 solo existía DENTRO del brazo (X 166-196,5). La
interferencia salió limpia justo porque no se tocaban. En la lámina frontal
hay una pieza negra de hombro entre ambos (medida a mano sobre rejilla,
`medicion_brazo/hombro_frontal.jpg`). Pecho 2.6.0: disco R47 (X 124-130,
entra 2 mm en el pecho), disco R39 (130-138), cuello R29 (138-146), disco R39
(146-157) y el eje R36,5 (157-196,5), coaxiales con el eje del hombro (en la
lámina se dibujan inclinados con el brazo). La carcasa del brazo no baja de
X 159,3 (esquinas de sus perfiles ya colocados): los discos acaban en 157 y
solo el eje entra; el taladro del brazo (v13c) empieza en 155. Pruebas: los
discos a >= 2 mm de la carcasa, la pieza continua, el eje dentro del taladro
y los mismos números en el complemento del pecho y aquí (se lee su código).
Complemento del pecho copiado a `%APPDATA%` (respaldo de la 2.5.0 en el
scratchpad de la sesión). Al ejecutarlo en el montaje restablece los
parámetros del pecho a los de por defecto (340/190/220).

## v13b: RESULTADO en el montaje — 28-09-2026 — hombro sin tocar el pecho

Generado (todo a 0,0 mm), guardado como `Toreto_Brazo_Mano_v13b` y reemplazado
en el montaje `…_backup`; juntas de la mano izquierda rehechas (20 juntas, 16
relaciones, pasadores a 0,001 mm; Fusion añadió ' (2)' a nombres de cuerpos
de la copia y `base_name` lo absorbió). **Interferencia pecho-brazo: la fila
del conector contra la carcasa ha desaparecido en los dos brazos.** Quedan
solo las ajenas al encaje (pecho consigo mismo, rótula-conector de palma,
mano sin recortar).

## v13b: taladro del hombro prolongado, preparada el 28-09-2026

Interferencia en el montaje (los dos brazos, simétricos): la única pieza del
brazo que toca el pecho es su carcasa `01_BRAZO_LOCAL_SIN_REBAJES` contra
`PECHO95_07_CONECTOR_HOMBRO_DER/IZQ`, 1806,8 mm3. El taladro de la v13 empezaba
en X 167,4 y el conector en 166; además la carcasa baja inclinada ~15° y, por
encima y por debajo del taladro, su cara interior llega más cerca del pecho.
Arreglo: el taladro va de X 164,0 a 224,6 (2 mm más allá de cada extremo),
coaxial y con R37,3 > R36,5: el conector queda entero dentro del cilindro que
se quita a la carcasa, así que no puede tocarla (prueba
`test_connector_lies_entirely_inside_the_bore`, que falla con el taladro de la v13).

El resto de la tabla es ajeno al encaje: piezas del pecho solapadas entre sí
(vienen de su generador), casquillos y pasadores sobre su propia falange
(bloque rígido), la palma sin recortar contra las primeras falanges (prueba
de la palma pendiente) y la rótula de la muñeca contra el conector de la palma
(9531 mm3; son una sola pieza en una muñeca de rótula: el script puso la
rótula en el antebrazo y el conector en la mano; corregir al hacer las juntas
del brazo).

## v13: RESULTADO en Fusion — 27-09-2026 — hombro encajado, dos brazos articulados

`vista_brazo_v11.json` (modo ver_brazo, v13): pivote del hombro en el eje del
conector (0,0 mm), tapa del hombro y rótula a 0,0 mm dentro de Fusion, mano
en su sitio (0,0 mm, con la comprobación corregida). El usuario lo guardó
como `Toreto_Brazo_Mano_v13` y lo reemplazó en el montaje; la simetría del
brazo izquierdo se recalculó sola y sus juntas antiguas quedaron con errores
de referencia (geometría en caché). Se borraron y `juntas_espejo` las creó de
nuevo: 20 juntas y 16 relaciones, pasadores a 0,001 mm (`juntas_espejo_v12.json`).
Lección: al cambiar el brazo derecho, borrar las juntas de la mano izquierda
y volver a ejecutar `juntas_espejo`. Pendiente: Inspeccionar > Interferencia
entre brazo y pecho.

## v13: hombro encajado en el pecho, preparada el 27-09-2026 — SIN ejecutar

Pedido por el usuario tras confirmar que la mano izquierda cierra hacia su
palma. Conector del hombro derecho del pecho (`Toreto_Pecho_Hombros_95cm`
2.5.0 con parámetros por defecto: ancho 340, alto 190, base+tronco+cintura
540 mm): cilindro en X de 166 a 196,5 mm, Y 0, Z 690,83, radio 36,5 mm.

- El eje del hombro del brazo pasa a ser **coaxial con el conector**: X
  exacta (antes inclinado 15° con la carcasa) y pivote en Y 0, Z 690,83
  (16 mm del punto de la lámina: manda el pecho).
- Taladro del alojamiento R37,3 (conector + 0,8 mm), pared 7,7 mm; el
  alojamiento va de X 169,4 a 222,6, así que el conector entra en el brazo,
  como dibuja la lámina. El eje negro propio del brazo queda como tapa
  exterior desde X 197,3 (0,8 mm tras el extremo del conector).
- Postura reajustada alrededor del conector: hombro +19,6°, codo -48,0°;
  codo a 7,3 mm y final del antebrazo a 3,6 mm de la lámina.
- `chest=None` reproduce la v11 exacta (probado). 57 pruebas; simuladores OK.
- Sin comprobar: que los parámetros del pecho del montaje sean los de por
  defecto, y si la carcasa del brazo toca el pecho (Inspeccionar >
  Interferencia en el montaje).
- La v12 (juntas de la mano izquierda) calcula con esta postura: al cambiar
  el brazo derecho hay que rehacer la simetría y volver a ejecutarla.

## v12: RESULTADO en el montaje — 27-09-2026 — mano izquierda articulada

`juntas_espejo_v12.json`: 20 juntas y 16 relaciones creadas en la mano copiada
por simetría; los 20 pasadores a 0,001 mm con la colocación `transform2` (la
cadena de padres dio lo mismo; la identidad, 914 mm). El usuario comprobó
en Fusion que las relaciones se mueven. El robot tiene ya los dos brazos v11
con manos de 4 motores articuladas. Pendiente: el encaje del hombro en el
pecho (16 mm en Y y el taladro menor que el conector de 36,5 mm) y las juntas
del brazo, en el orden decidido: piezas → dimensiones → límites.

## v12: primera ejecución en el montaje — 27-09-2026 — RECHAZADA SIN CAMBIOS

La protección funcionó: encontró la mano copiada
(`06_MANO_ARTICULABLE(Simetría)`), sus 21 piezas y el pasador, pero midió
(272,6; -79,9; -313,9) donde esperaba (-272,6; -79,9; 313,9): el mismo punto
con X y Z cambiados de signo. Fusion guarda la mano reflejada dentro de su
componente y coloca el componente girado 180° en Y; el script leía los
bordes en coordenadas internas y comparaba con las del robot. Corregido: se
prueban las colocaciones candidatas (`transform2` de la ocurrencia, la cadena
de padres y la identidad), se pasan centros y ejes a coordenadas internas
(`to_local_specs`; un eje es pseudovector también aquí) y solo vale la que
cuadra los 20 pasadores. La medición real es ahora una prueba unitaria. El
simulador cubre el caso real, el anidado y los dos sentidos del círculo, y
sigue rechazando la mano girada sin datos de colocación.

## v12: juntas de la mano izquierda, preparada el 27-09-2026

Montaje real: documento `Toreto_hombro_encajado_sin_articulaciones`. El
usuario borró el brazo antiguo, insertó el v11 guardado como
`Toreto_Brazo_Mano_v11` y creó el izquierdo con Crear > Simetría (plano YZ).
La copia no tiene juntas ni relaciones. `MODE='juntas_espejo'` se las añade.

**Excepción autorizada por el usuario** a "solo documento vacío": este modo
trabaja en el montaje, pero NO crea ni mueve geometría; solo añade 20 juntas
y 16 relaciones a la única `06_MANO_ARTICULABLE` sin juntas. Antes de crear
nada comprueba que haya exactamente una, sus 21 piezas por nombre (admite el
sufijo "(Simetría)"), los 20 pasadores en su pieza, cada uno a menos de
1,5 mm de su posición reflejada y con su borde circular alineado. Si algo
falla, no cambia nada. Se pidió guardar una versión del montaje antes.

Al reflejar, el eje de giro no va a M·a sino a -M·a (pseudovector): con M·a
los dedos izquierdos se doblarían hacia fuera. Probado en
`test_mirror_joints.py` (y una prueba impide "simplificarlo").
`simular_espejo_sin_fusion.py`: 20 juntas y 16 relaciones con los dos
sentidos posibles del círculo reflejado, pinza reflejada dentro de límites,
y rechazo sin cambios con mano desplazada, dos manos libres o un pasador
ausente; detecta el eje reflejado como punto. No comprobado: cómo nombra y
coloca Fusion las copias por simetría (si difiere, el script se negará y lo
dirá en `juntas_espejo_v12.json`).

## v11: RESULTADO en Fusion — 27-09-2026 — brazo colocado como la lámina

`vista_brazo_v11.json`: publicado; 20 juntas y 16 relaciones de la mano
creadas con los ejes girados. **Eje del hombro y rótula a 0,0 mm de donde
deben estar, medido dentro de Fusion.** El aviso dio "mano en su sitio: NO"
(peor falange 2,055 mm), pero era un fallo de la comprobación: giraba el
centro de la caja alineada con los ejes, y esa caja cambia al girar una pieza
asimétrica. Lo delata el patrón: depende de la forma (falanges tipo caja
~0,12 mm, las cuatro puntas idénticas ~0,9 mm, falange 1 del pulgar 2 mm),
no de la distancia a la muñeca; y los 20 pasadores se encontraron con sus
ejes girados. Corregido: la pieza calculada se gira y luego se mide su caja.
Pendiente: comparar el lateral con la lámina a ojo.

## v11: brazo como la lámina, preparada el 27-09-2026

Decisión del usuario: el brazo toma ya las medidas de la lámina (se ajustará
con los servos) y se construye en su postura, que será el cero de las juntas.
Medición en `medicion_brazo/MEDICION_BRAZO_LAMINA.md`. `MODE='ver_brazo'`
publica brazo y mano abierta; los demás modos no cambian.

- `toreto_arm_pose.py` (puro): alarga el antebrazo ×1,365 (del codo al final
  de la carcasa, 164 mm como la lámina) dejando fijo el extremo del codo y
  con los MISMOS perfiles estables (sin forzarlo entraba uno más: lo detectó
  una prueba); lleva el eje del hombro a su pivote (156,6 mm del codo) con un
  alojamiento del ancho de la carcasa (51,3 mm) y el radio del disco de la
  lámina (45 mm); y calcula los giros de la postura: hombro +13,6°, codo
  -44,0°. Frente a la lámina: hombro 0 mm, codo 2,5 mm, final del
  antebrazo 7,3 mm (sobre todo en X).
- Todo se construye en el marco plano de siempre y, antes de importar, brazo
  superior, antebrazo y mano se mueven con giros rígidos. Los ejes de las
  juntas de la mano se transforman igual. La mano y sus ensayos no cambian.
- El JSON (`vista_brazo_v11.json`) comprueba en Fusion dónde quedan el eje
  del hombro y la rótula, y cada falange frente al cálculo.
- Validación: 45 pruebas; `simular_brazo_sin_fusion.py` con cuerpos falsos
  que sí se mueven, que detecta (probado rompiéndolo): ejes de la mano sin
  girar, mano sin colocar, matriz traspuesta, traslación en mm en vez de cm
  y antebrazo con la matriz del brazo.
- No comprobado: el loft del antebrazo alargado y el alojamiento del hombro
  en Fusion, ni si las carcasas de brazo y antebrazo se tocan en el codo con
  -44° (eso es el siguiente paso: juntas del brazo y ensayo de recorridos).

## v10b: RESULTADO en Fusion — 27-09-2026 — pinza lateral ACEPTADA

`prueba_mano_4_motores_v10b.json`: estado `contacto_cara_no_deseada_o_indeterminada`
porque el ensayo esperaba el costado PLANO del índice. Datos: primer contacto
entre 77,9% y 78,1% del índice (pulgar 20,3%), sin choques antes; pulgar
**palmar** (37-63% de la falange, alineación 0,97); índice en la **punta**
(69-89% de su falange, zona redondeada, cerca de la esquina costado/palmar);
intersección 0,163 mm3 frente a 2,955 mm3 de penetración por diferencia
(confirmada la hipótesis: la diferencia es ruido en contactos rozantes; a
83% coinciden, 89,9 mm3). La "estabilidad NO" no es informativa: las otras
posturas comprobadas tenían 40 y 550 veces más solape (fallo de diseño del
chequeo: debían ser posturas pegadas al contacto).

Vista en Fusion (modo `ver_pinza` + juntas a mano: cardán -30, pulgar -8,125,
índice 42,188): la cara plana del pulgar toca la esquina redondeada de la
punta del índice y se abre una V de unos 20-30°. **El usuario la acepta tal
cual** (`docs/DECISIONES.md`); yemas blandas y rugosas previstas.

## v10b: cara del contacto, preparada el 27-09-2026

**Resultado de la v10 en Fusion (27-09-2026): `cara_no_resuelta`**, con lo
demás bien: 0 choques en las muestras 0-9 (2.743 pares, 34 cuerpos móviles)
ni en el afinado; primer contacto SOLO entre `09_PULGAR_FALANGE_3` y
`07_DEDO_1_FALANGE_4`, acotado entre el 77,9% y el 78,1% del índice
(flexión del pulgar 20,3%, cardán 100%). Toques con contacto: 78,1%, 79,2%
y 83,3%, coherentes. Falló la comprobación "volumen de intersección no
coincide con la penetración", y el error no guardó los volúmenes. Hipótesis
(sin confirmar): en un contacto rozante, la penetración por diferencia resta
dos volúmenes de miles de mm3 y la imprecisión del cálculo de volumen la
desbarata; la intersección directa es la fiable. Informe conservado:
`prueba_mano_4_motores_v10.json`.

Cambios de la v10b (misma geometría, mismo escenario, mismo afinado):
- Manda la intersección directa; los dos volúmenes se guardan siempre y la
  diferencia pasa a aviso (`warnings`). Intersección <= 0,01 mm3: contacto
  no confirmado, nunca apoyo.
- La cara se clasifica en hasta 3 posturas con contacto (la más temprana
  decide; las otras dan `stability.consistent`). Apoyo palmar-lateral sin
  estabilidad confirmada: `apoyo_palmar_lateral_sin_confirmar_estabilidad`.
- Informe: `prueba_mano_4_motores_v10b.json`.
- Simulador: 8 casos, incluidos volumen discrepante (lo de la v10) e
  intersección vacía; con la comprobación estricta de la v10 falla.

## v10: pinza lateral, preparada el 27-09-2026 — SIN ejecutar en Fusion

`MODE='ensayo_lateral'`: cardán al 100% desde la muestra inicial; índice a
`t` y flexión del pulgar a `0,26*t`, en 12 divisiones. Se conservan las
relaciones, topes y geometría de la v8/v9. Solo se ejecuta este escenario;
la mano abierta y los motores solos de la v8 no se repiten ni se atribuyen a
la v10. Criterio: ningún choque ajeno antes del primer contacto de falanges
pulgar-índice.

En ese primer contacto muestreado, el ensayo intersecta los **sólidos
temporales reales** y registra volumen y caja de la intersección; la sitúa en
el marco de la falange final del pulgar y del índice. Distingue palmar,
dorsal, lateral, punta y transiciones/esquinas indeterminadas. Si contacta
otra falange o falla el booleano, no concede apoyo palmar. La caja localiza
la zona, pero no mide área de apoyo ni sustituye la inspección visual.

**Afinado del contacto (añadido el 27-09-2026, antes de ejecutar).** Con 12
divisiones el índice avanza 8 puntos por muestra; en la v8 eso llevó de 15 a
868 mm3 entre dos muestras, y un solape así invade esquinas y deja la cara
indeterminada. Al aparecer el primer contacto, el ensayo biseca 5 veces entre
la última muestra limpia y esa (paso final ~0,26% del índice) y clasifica la
cara en la postura más temprana con choque. Si en ese tramo aparece antes un
choque ajeno a la pinza, lo informa como previo. Las 13 muestras no cambian.
JSON: `refinement`, `refined_bracket` y `first_contact.fraction` (afinada;
`coarse_fraction` es la de la muestra).

Validación previa: 33 pruebas unitarias; simulador sin Fusion con contacto
palmar, contacto dorsal, choque previo, ausencia de contacto, error de
intersección y choque entre muestras (solo visible con el afinado; el
simulador falla si se desactiva), todos con informe JSON legible. Esos contactos son inventados;
**no hay resultado geométrico de la v10 todavía**. Informe esperado al
ejecutarla: `prueba_mano_4_motores_v10.json`. Si sale bien, la vista 3D con
recálculo de pose queda para otra ejecución, no esta.

## v9: vista de la pinza en 3D — 2026-09-26, ejecutada en Fusion

No es un ensayo: publica la mano de la v8 en el documento vacio para
mirarla (`MODE='ver_pinza'` en el script; `MODE='ensayo'` repite la v8).
Pose: muestra 9 de 12 de la pinza de la v8 (75%, hueco 0,28 mm), la ultima
antes del contacto, para ver si tocan por la yema o por el canto.

- 4 motores en Fusion: 16 relaciones, cada seguidora directa a su maestra
  (`JUNTA_DEDO_1_1`, `JUNTA_DEDO_2_1`, `JUNTA_PULGAR_2`); cardan suelto.
- Sin `clearance.repair()`: palma sin recorte y NO validada.
- `vista_pinza_v9.json`: angulos leidos de vuelta de Fusion y posicion de
  cada falange frente al calculo del ensayo (`pose_igual_al_ensayo`).
- Validado fuera de Fusion: 25 pruebas y `simular_publicacion_sin_fusion.py`,
  que detecta un signo de relacion o de pose mal puesto (comprobado
  rompiendolos a proposito). No puede comprobar el sentido de giro real de
  Fusion: si un dedo se dobla hacia atras, lo delatara la comparacion de
  posiciones del JSON.

**Primera ejecucion (26-09-2026): ERROR** al crear las juntas, con las
piezas ya importadas: "No se encontro un borde circular alineado en el
pasador". Causa: `pin_axis_edge()` buscaba siempre un pasador de 4 mm, pero
`JUNTA_PULGAR_1` y `_2` lo tienen de 2,8 mm (`hinge_dimensions`). Ese
codigo de publicacion era anterior a la reduccion del pasador del pulgar.
El simulador tampoco lo vio: creaba todos los pasadores de 4 mm. Corregido
en ambos: radio por junta en el script; en el simulador, radio real mas
circulos senuelo, y ahora reproduce el error con el codigo antiguo.

**Segunda ejecucion (26-09-2026), en documento de diseno HIBRIDO: PUBLICADA.**
101 cuerpos, 21 componentes, 20 juntas, 16 relaciones. `vista_pinza_v9.json`
dio `pose_igual_al_ensayo: NO`: las juntas guardaron los valores exactos
(indice 40,5; cardan y flexion del pulgar 30), pero las piezas seguian en la
postura abierta (comprobado: la hipotesis "nada se movio" encaja a 1,7 mm;
las de signo invertido fallan por 40-86 mm). Fusion aplico esos valores
guardados en cuanto el usuario acciono una junta a mano: al script le falta
forzar el recalculo tras la pose (pendiente, sin validar).
En la interfaz, "Animar relaciones de union" mueve cada dedo entero: las
relaciones de los 4 motores funcionan. El indice "atravesando" el pulgar al
animarlo era la pinza pasada del contacto (el pulgar ya estaba a -30/-30).

**Lo que se ve en la pinza al 75%:** el pulgar toca de PUNTA (extremo curvo
de su falange 3) contra la cara interior de la ultima falange del indice,
junto a su ultima articulacion. El usuario: el indice esta bien; el PULGAR
debe apoyar con la cara plana de su ultima falange, no con la curva (mas
superficie, el boli no gira). Caras de agarre rugosas. Ver
`docs/DECISIONES.md`. Cambiar la postura del pulgar exige ensayo nuevo.

Pista previa de los datos de la v8: en la muestra 11 la punta del indice
entra 868 mm3 en la falange MEDIA del pulgar, no en su punta: el indice
podria pasar por encima de la punta del pulgar (contacto de canto).

## v8: RESULTADO en Fusion — 2026-09-26 19:17 — TODO LIMPIO Y PINZA LOGRADA

`prueba_mano_4_motores_v8.json`: estado `todo_limpio_y_pinza_lograda`.
0 errores del nucleo en todo el ensayo, 50 apoyos verificados.

- Mano abierta, indice solo, corazon+anular+menique (senalar), flexion del
  pulgar sola y rotacion del pulgar sola: LIMPIOS. El choque de la v7 del
  indice contra la falange 1 del pulgar ha desaparecido.
- Pinza del boli: LOGRADA, punta con punta (07_DEDO_1_FALANGE_4 /
  09_PULGAR_FALANGE_3), cero choques antes del contacto. Contacto en la
  muestra 10 (83% del cierre) frente al 67% de la v7, como se esperaba al
  avanzar el indice mas despacio. Hueco entre puntas (mm): 77,7 / 69,1 /
  60,1 / 50,9 / 41,9 / 33,6 / 24,9 / 15,1 / 6,5 / 0,28 / 0 / 2,4 / 7,8.
  Un boli de ~8 mm quedaria sujeto hacia la muestra 8. De los 8 pares del
  escenario, uno es el propio contacto y 7 aparecen solo despues: artefacto
  de la simulacion (la mano real se detiene al tocar).

Lo que esto NO valida, y sigue pendiente: la palma principal (excluida del
ensayo), la holgura continua entre las 13 posturas muestreadas, la
resistencia, los agarres de objetos (vaso, pelota), el mecanismo de tendones
(que aun no existe en el diseno) y si la pinza toca por la yema o por el
canto. Es el primer resultado limpio de la mano, NO una mano funcional
validada ni lista para fabricar.

## v8: el indice con su propio recorrido — 2026-09-26, preparada

Unico problema de la v7: el indice, al cerrar del todo con el pulgar en
reposo, tocaba su falange 1 (5,2 mm3, solo en la muestra 12).

Cambio: el indice recorre el 90% que los demas dedos, en sus cuatro
articulaciones por igual: 54/54/45/36 grados en vez de 60/60/50/40
(`INDEX_FLEXION_LIMITS_DEG` y `finger_flexion_limits()` en `toreto_hand.py`).
Se aplica a la cinematica y a la posicion de los topes fisicos de las
bisagras. Corazon, anular, menique y pulgar sin cambios.

Por que uniforme: con la misma escala en las cuatro articulaciones, el nuevo
recorrido del indice es exactamente el tramo 0-90% del de la v7, que se
midio limpio hasta el 91,7% (muestra 11). Lo comprueba una prueba unitaria,
y otra impide subir la escala por encima de lo medido limpio.

Se repiten los cinco escenarios: los topes son geometria presente en toda
postura, y moverlos podria crear contacto con el dedo vecino. Se espera que
la pinza siga lograndose, algo mas tarde en el cierre (el indice avanza mas
despacio en proporcion al pulgar).

Verificado fuera de Fusion: 19/19 pruebas unitarias y el flujo completo en
el Fusion simulado. Informe: `prueba_mano_4_motores_v8.json`.

## v7: RESULTADO en Fusion — 2026-09-26 18:42

`prueba_mano_4_motores_v7.json`. 0 errores del nucleo, 50 apoyos verificados.

- Mano abierta: limpia. La correccion del taladro funciona: desaparece el
  unico choque con mano abierta de la v6 (casquillo/pasador del nudillo 1).
- Rotacion del pulgar sola, flexion del pulgar sola, y corazon+anular+menique
  (postura de senalar): limpios.
- Pinza del boli: LOGRADA. Primer contacto en la muestra 8 (66,7% del
  cierre) entre 07_DEDO_1_FALANGE_4 y 09_PULGAR_FALANGE_3, punta con punta,
  sin ningun otro choque antes. Hueco entre puntas (mm) por muestra:
  77,7 / 68,3 / 58,4 / 48,2 / 38,3 / 29,0 / 18,3 / 7,6 / 0 / 0 / 0 / 5,4 / 11,3.
  measureMinimumDistance funciona con cuerpos temporales. Los 19 pares que
  aparecen despues del contacto son artefacto de la simulacion (la mano real
  se detiene al tocar). No se sabe si el contacto es por la yema o por el
  canto: requiere una vista 3D.
- Indice solo: UN choque, 5,184 mm3, solo en la muestra 12 (cierre total)
  entre 07_DEDO_1_FALANGE_4 y 09_PULGAR_FALANGE_1 en reposo. Limpio hasta
  la muestra 11 (92%). Es el dedo mas cercano al pulgar.

Frente a la v6 (58 pares), queda un unico par real. Sigue sin validar: la
palma principal, holgura continua, resistencia, agarre de objetos y el
mecanismo de tendones. No es una mano funcional validada.
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

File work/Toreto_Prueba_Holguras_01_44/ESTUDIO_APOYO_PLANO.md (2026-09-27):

# Criba del apoyo plano del pulgar — 27-09-2026 (corregida)

Estudio **fuera de Fusion**. No cambia `toreto_hand.py`, las relaciones ni el
documento CAD. Se reproduce con `study_thumb_pad.py`, que usa
`hand_local_sections.json`, los ejes de `joint_specs()` y el mismo orden de
rotaciones que el ensayo v8. Se examinan las cuatro parejas de caras
longitudinales de las dos falanges finales. **Cada cara se clasifica por la
dirección en la que dobla su última articulación**: palmar hacia dentro de
la curva, dorsal hacia fuera; las dos perpendiculares son laterales. El índice
conserva su geometría y reparto de flexión; solo se varía su fracción de
cierre para encontrar el momento de contacto.

La v9 estaba al 75% del cierre del índice, con pulgar 30/30/26,25/15 grados
(cardán / juntas 2–4). El par de caras planas más cercano en esta aproximación
queda a 2,44 mm, con 43,6 grados de desalineación y el punto del pulgar en un
borde lateral. Esa cara del pulgar es **dorsal**, por lo que el dato no sirve
para decidir el agarre pedido. La observación visual fue contacto por la
punta. Esta aproximación **no reproduce el hueco exacto de 0,28 mm** medido
entre sólidos: son superficies y métricas diferentes.

La criba usa una malla de 5 grados para cada junta del pulgar dentro de los
topes actuales y exige: distancia de puntos <=2 mm, normales opuestas dentro
de 45,6 grados, puntos dentro de la zona longitudinal plana y fuera de los
bordes laterales. A 65% y 75% del índice no hay candidatos; a 80% hay tres
parejas de caras que pasan la criba, a 83% diez. La criba inicial no filtraba
la identidad de la cara; estos recuentos **no son pinzas válidas ni validadas**.

| Caso | Índice | Pulgar 1/2/3/4 | Caras que se acercan | Distancia aprox. | Desalineación | Dictamen |
|---|---:|---|---|---:|---:|---|
| A | 83% | 30/10/5/5° | palmar / lateral | 0,38 mm | 22,7° | Única de las tres que usa la cara de agarre del pulgar; puede ser una pinza tipo boli contra el costado del índice. |
| B | 83% | 25/40/15/5° | dorsal / lateral | 0,46 mm | 35,4° | Descartada: apoya el dorso del pulgar. |
| C | 80% | 25/20/35/20° | dorsal / palmar | 0,75 mm | 41,5° | Descartada: apoya el dorso del pulgar. |

**A no exige cambiar relaciones.** Con el cardán a 30° y el motor de flexión
del pulgar al 25%, las proporciones actuales producen 30/10/8,75/5°. Al 83%
del índice, la aproximación da 0,44 mm y 21,7° entre cara palmar del pulgar y
lateral del índice. Esta postura no supera el criterio de *punto interior* de
la criba: el par más cercano cae al 64% de la longitud plana del pulgar y al
18% de la del índice, cerca de sus extremos respectivos. En una búsqueda fina
con las mismas relaciones, 84% del índice y 21% de flexión da un par interior
a unos 0,31 mm y 22,8°, pero sigue siendo solo una predicción geométrica.

Para dos caras **palmares**, un barrido angular sin prueba de distancia da una
desalineación mínima de 69,1° con el índice al 75%, 73,9° al 80% y 79,0° al
85%. Así, en la región de la pinza actual, los ejes no ofrecen buen apoyo
palmar-palmar. Matiz importante: con el índice *abierto* sí aparece una
orientación de 39,7°, pero las piezas están lejos; por tanto el cálculo no
demuestra imposibilidad geométrica absoluta en toda postura, sino falta de
una pinza palmar-palmar cercana con la configuración estudiada.

Las distancias son entre puntos muestreados de caras idealizadas, **no**
holguras medidas por el núcleo geométrico. El loft real tiene esquinas
redondeadas y punta curvada. No se han comprobado intersecciones de sólidos,
recorrido continuo, palma, nudillos, apoyo sobre un boli, resistencia ni
agarre de vaso/pelota. Tampoco se ha demostrado un área de apoyo suficiente:
incluso A conserva unos 22° de desalineación. La variante A con relaciones
actuales no cambia topes ni acoplamientos; B y C se descartan antes de
considerar cambios mecánicos.

Siguiente paso, **solo tras aprobación**: ensayar con sólidos únicamente A
con las relaciones actuales (índice 83%, cardán 30°, flexión del pulgar 25%),
medir hueco/contacto real y choques antes del contacto, forzar recálculo de
la pose y dejar una foto fija. Luego decidir si vale el apoyo palmar del
pulgar contra el lateral del índice para un boli; si se exige palmar-palmar,
estudiar el rediseño del mecanismo del pulgar. No tocar el índice ni publicar
sobre el diseño original; detenerse ante cualquier desplazamiento inesperado.

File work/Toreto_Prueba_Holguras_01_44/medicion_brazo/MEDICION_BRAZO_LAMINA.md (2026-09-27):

# Brazo: medición sobre la lámina frente al brazo de prueba — 27-09-2026

Fuente maestra: los lienzos calibrados de `cad-toreto/toreto_fusion_95cm/
reference/lienzos_95cm/` (0,5 mm/px, Z=0 en el suelo). Brazo derecho del
robot. Y en el lienzo lateral derecho: negativo = hacia delante.

**Método.** Se amplió el brazo con una rejilla de 10 mm (imágenes de esta
carpeta) y se leyeron a ojo los centros: en el lateral los pivotes de hombro
y codo se ven como círculos (sus ejes van de lado a lado, eje X); la X de
cada punto se leyó en el frontal, en el eje de la carcasa a esa altura.
Precisión estimada: unos ±3 mm por punto. Las guías de Codex
(`fusion_traces.json`) se comprobaron dibujándolas sobre el lienzo lateral
(`guias_brazo.jpg`): siguen el brazo.

| Punto (lámina) | X | Y | Z |
|---|---:|---:|---:|
| Centro del hombro | 196 | 16 | 690 |
| Pivote inferior del brazo superior | 228 | 47 | 575,5 |
| Pivote superior del antebrazo | 239,5 | 58,6 | 509,5 |
| Fin de la carcasa del antebrazo | 265 | -27,5 | 402,5 |
| Muñeca | 268 | -34 | 389 |

**Codo:** los dos círculos pequeños (68 mm entre sí) son las fijaciones de
la pieza negra de enlace a cada carcasa; **el giro es un solo eje, en el
centro de esa pieza** (aclarado por el usuario el 27-09-2026). Por eso se
compara el codo del brazo de prueba con el punto medio entre ambos círculos.

| Tramo | Lámina | Brazo de prueba |
|---|---:|---:|
| Hombro → centro del codo | 156,6 mm | 211,3 mm |
| Centro del codo → muñeca | 179,6 mm | 124,3 mm |
| Total | 336,3 mm | 335,7 mm |
| Inclinación hacia delante: brazo / antebrazo | -15° / +37,5° | 0° / 0° |

Diferencias del brazo de prueba respecto a la lámina:

- **Hombro 67 mm desplazado**: 52 mm más alto y 39 mm hacia atrás. Su eje
  está en lo alto de la carcasa (Z 742), no en el pivote dibujado (Z 690).
- **Codo bien**: a 4,8 mm del punto medio entre los dos pivotes.
- **Muñeca 93 mm desplazada**: 88 mm hacia atrás y 29 mm más alta, porque
  el antebrazo está recto en el plano frontal en vez de inclinado ~38°.
- El largo total coincide, pero está mal repartido: el brazo superior sobra
  ~55 mm y al antebrazo le faltan ~55 mm.

Causa: el generador (`Toreto_Brazo_Marcos_Locales_95cm`) toma la postura y
las longitudes de la vista frontal, donde el antebrazo inclinado se ve
acortado, y usa la lateral solo para el grosor.

Incertidumbre: los dos lienzos laterales no coinciden del todo (el antebrazo
sale a 38° en el derecho y a 46° en el izquierdo según las guías). Es un
dibujo, no un plano: tomar estas cotas con ±5-10 mm.

Brazo del montaje (`Toreto_Brazos_95cm` 3.9.0), por lectura del código, sin
comprobar en Fusion: modela la inclinación (brazo ~14° atrás, antebrazo ~35°
adelante) con un solo eje de codo; parámetros `largo_brazo` 178 mm y
`largo_antebrazo` 186 mm. Su antebrazo parece más largo que el de la lámina
(~190-200 mm del eje del codo al final de la carcasa frente a ~164 mm);
pendiente de medirlo en Fusion.

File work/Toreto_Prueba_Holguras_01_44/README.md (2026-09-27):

# Reparacion experimental de mano — punto de control

Estado: **trabajo en curso, no funcional ni listo para fabricar**.

Esta carpeta contiene el generador aislado y los diagnosticos reproducibles.
No sustituye al generador principal ni modifica el robot original.
Ejecutar solamente desde Fusion en un documento de prueba vacio. El script
rechaza documentos con cuerpos u ocurrencias. El modo activo v10 retorna
sin publicar un ensamblaje ni guardar documentos de Fusion.

## v10b (27-09-2026) — ejecutada: pinza lateral aceptada

La v10 abortó al clasificar la cara (volúmenes de penetración e intersección
distintos en un contacto rozante). La v10b añade el afinado del contacto,
manda la intersección directa y guarda ambos volúmenes. Resultado: sin
choques antes del contacto; cara plana del pulgar contra la esquina de la
punta del índice. Aceptada por el usuario. Informes:
`prueba_mano_4_motores_v10.json` y `..._v10b.json`. Simulador:
`python simular_lateral_sin_fusion.py` (8 casos).

## v10 (27-09-2026) — descripción original del ensayo

`MODE='ensayo_lateral'` (valor actual). Un único escenario nuevo: cardán al
100% desde el principio; índice a `t` y flexión del pulgar a `0,26*t`, con
12 divisiones. No altera `toreto_hand.py`, topes, relaciones de movimiento ni
los cinco escenarios de la v8. Ensaya todos los pares móviles salvo la palma
principal y se detiene al primer contacto pulgar-índice o al primer choque
ajeno. En el primer contacto medido toma la intersección BRep real y sitúa su
caja respecto a la última falange del pulgar y del índice; clasifica palmar,
dorsal, lateral, punta o ambiguo. Si toca otra falange, lo informa; un fallo
del núcleo no cuenta como ausencia de choque. Informe previsto:
`prueba_mano_4_motores_v10.json`. Aún no existe resultado de Fusion.

Antes de pedir esa ejecución: 33 pruebas unitarias y
`simular_lateral_sin_fusion.py` pasan. El simulador inventa contactos y
choques para recorrer las ramas; **no valida geometría**. La v10 tampoco
demostrará holgura continua, palma, área de contacto, resistencia ni agarre
de objetos. No publica una vista 3D: eso sería otra ejecución, solo si el
ensayo sale bien.

## v9 (26-09-2026) — vista de la pinza, ejecutada en Fusion

Excepcion deliberada a "no publica": con `MODE='ver_pinza'` (modo histórico)
el script crea la mano con 20 juntas y los 4 motores como relaciones de
movimiento, y la deja en la pinza al 75%. Solo en documento vacio; palma sin
recorte y NO validada. Informe: `vista_pinza_v9.json`. Con
`MODE='ensayo'` repite el ensayo de la v8 sin crear piezas.
Simulacion previa: `python simular_publicacion_sin_fusion.py`. Fusion guardó
los ángulos pero no propagó los cuerpos hasta que el usuario accionó una
junta; la pose visual se comprobó a mano. Véase `RESULTADO_PRUEBA.md`.

## v8 (26-09-2026) — ejecutada: todo limpio y pinza lograda

La v7 dio: mano abierta limpia, rotacion y flexion del pulgar limpias,
corazon+anular+menique limpio, y la pinza del boli lograda punta con punta
sin choques previos. Quedaba un unico choque: el indice, al cerrar del todo,
tocaba la falange 1 del pulgar en reposo (5,2 mm3). La v8 reduce el
recorrido del indice al 90% (54/54/45/36 grados) en su cinematica y en sus
topes fisicos. Detalle y justificacion en `RESULTADO_PRUEBA.md`. Informe:
`prueba_mano_4_motores_v8.json`. Pruebas unitarias: 19.

## v7: mano de 4 motores (26-09-2026)

Decision del usuario: la mano debe coger como una humana (boli con pulgar e
indice, pelota pequena, vaso). Un motor rigido no puede; se pasa a una mano
adaptativa de CUATRO motores: indice / corazon+anular+menique / flexion del
pulgar / rotacion del pulgar (el cardan). Ver `toreto_motor_groups.py`.

Se sustituye el cierre simultaneo de toda la mano: con cuatro motores no es
el movimiento real, y exigia que el pulgar no entrase en los dedos al cerrar
los cinco a la vez hasta el final, algo que ninguna mano con pulgar oponible
puede hacer (en la v6, 55 de 58 choques estaban en el tramo final del
cierre y el 87% del volumen era pulgar contra puntas).

La v7 prueba, en una sola ejecucion (`toreto_motor_validation.py`):
- mano abierta, todos los pares;
- cada motor solo, con el resto quieto y abierto: criterio CERO choques.
  El barrido de corazon+anular+menique con el indice quieto es la postura
  de SENALAR; el del cardan comprueba la correccion del taladro;
- pinza del boli: si las falanges de pulgar e indice llegan a tocarse,
  cuando, y si choca algo mas antes.
Registra el volumen muestra a muestra, no solo el maximo. Informe:
`prueba_mano_4_motores_v7.json`.

No comprueba la palma principal (excluida, como en la v6), ni holgura
continua, ni resistencia, ni agarres de objetos (vaso, pelota): eso
necesita simular el objeto y queda para la siguiente version.

## Resultado anterior (26-09-2026)

- Bisagras de los cuatro dedos estrechadas a 13.5 mm y pasadores con 0.25 mm
  de saliente; alojamientos de casquillos y extremos de falanges corregidos.
- Las tres falanges del pulgar reciben tambien alojamientos.
- `prueba_alojamientos_pulgar_v3.json`: 13 posturas sincronizadas, 65 pares
  con penetracion >0.01 mm3, cero errores del nucleo y 47 apoyos comprobados.
- No mover centros ni aplicar al original sin validar el conjunto.
- Pendientes: mecanismo de base del pulgar, choques durante el cierre,
  nueva prueba de palma con dimensiones actuales, movimiento independiente
  de dedos, holgura continua, resistencia y validacion visual del ensamblaje.

Los apoyos comprobados son controles geometricos heurísticos, no calculos
de resistencia. Los resultados anteriores de palma no certifican esta version.
`RESULTADO_PRUEBA.md` conserva la cronologia de ensayos, incluidos rechazos.

## Pruebas locales

`python -m unittest discover -s work/Toreto_Prueba_Holguras_01_44 -p "test_*.py" -v`

Treinta y tres pruebas: las veinticinco previas más ocho del escenario y de
la clasificación de caras de la v10 (`test_lateral_pinch.py`). Una de las
pruebas anteriores garantiza
que, con todos los motores a la misma fraccion, la postura es identica a la
del ensayo sincronizado anterior: la v7 no cambia la cinematica. No
reemplazan los ensayos BRep en Fusion.
Los JSON son resultados de diagnostico, no un archivo F3D de la mano.

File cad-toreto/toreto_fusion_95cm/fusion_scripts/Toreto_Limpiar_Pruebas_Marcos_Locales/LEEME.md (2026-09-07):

# Limpieza de pruebas de brazo por marcos locales

Este script elimina exclusivamente las ocurrencias superiores cuyo nombre
cumpla `94_BRAZO_MARCOS_LOCALES_PRUEBA_01_<numero>`, salvo la versión vigente
`94_BRAZO_MARCOS_LOCALES_PRUEBA_01_35`.

No modifica componentes con otros nombres, cuerpos del robot original ni
lienzos. Después de ejecutarlo, guarda y vuelve a abrir el documento para que
Fusion libere memoria y reconstruya únicamente los componentes conservados.

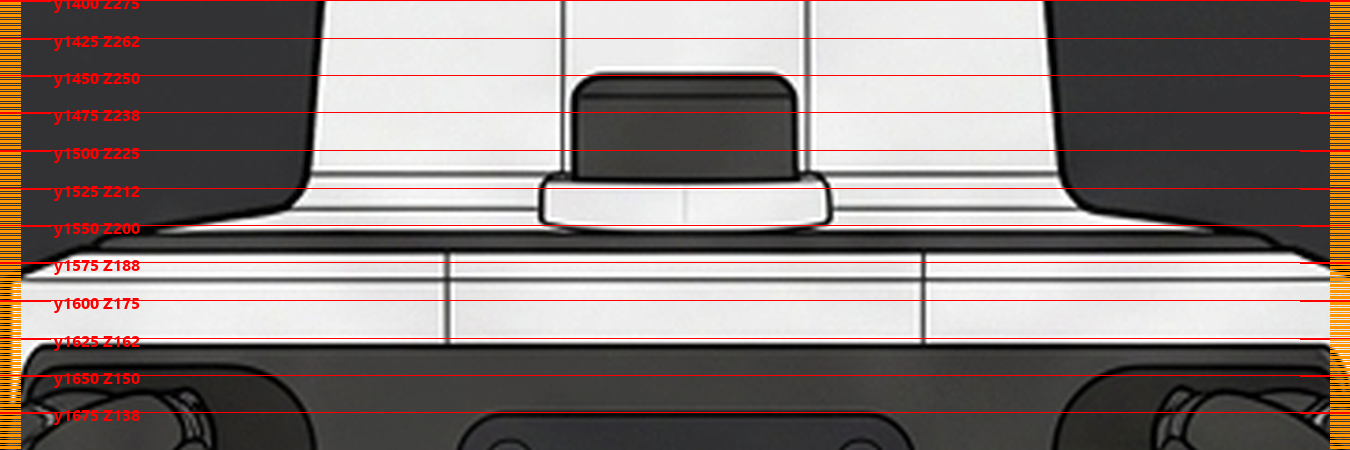
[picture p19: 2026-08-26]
cad-toreto/toreto_fusion_95cm/reference/lienzos_95cm/_measure/zoom_trunk_base.png

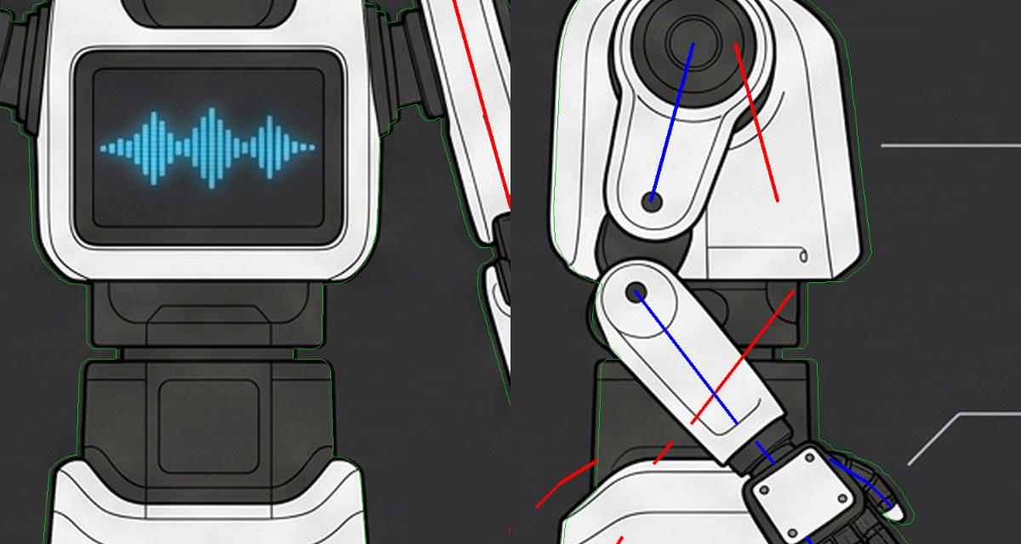
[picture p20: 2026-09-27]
work/Toreto_Prueba_Holguras_01_44/medicion_brazo/guias_brazo.jpg

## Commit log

2026-08-23 Commit inicial: fase 1 (diseño) del robot Toreto
    - CAD paramétrico v0-v2 en OpenSCAD (cad-toreto/)
    - Lista de piezas, guía de impresión P1S, notas de cada versión
    - docs/DECISIONES.md: registro de decisiones (orden de fases, Fusion
    sustituye a OpenSCAD, cad-toreto-gpt descartada, IA local/nube pendiente)
    - README con estado del proyecto y enlaces a los documentos vivos
    [arm_shoulder_support_left.stl, arm_shoulder_support_right.stl, base_center_plate.stl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]
2026-08-23 Añade roadmap versionado
    docs/ROADMAP.md: v0.1 (diseño) a v3.0 (IA integrada), checklist por versión.
    El cuaderno de aprendizaje queda fuera del repo, deliberadamente privado.
2026-08-23 Añade árbol cinemático planificado (docs/CINEMATICA.md)
    Diagrama Mermaid de links/joints previstos para el URDF de fase 3 -- tipos
    de joint sí, ángulos y actuador como TBD hasta elegir servos en fase 2.
    No es AutoLISP/ezdxf/CAD-MCP: eso es tooling de AutoCAD, que no encaja con
    el flujo OpenSCAD -> Fusion de este proyecto.
2026-08-23 Añade skills toreto-cad-visual-identity y toreto-mechanical-tokens
    Sustituyen a toreto-visual-identity (ilustración SVG plana, descartada por
    decisión del usuario). Nuevo estándar: visores 3D en Three.js con PBR,
    Bento Grid oscuro, vistas ortogonales normalizadas. Documentado en
    docs/DECISIONES.md; docs/CINEMATICA.md actualizado para referenciar las
    skills nuevas en vez de la descartada.
2026-08-23 Base: 4 ruedas mecanum en vez de 3 omni
    Holonómica igual; altura y el resto de medidas no cambian. Actualizado
    README.md y docs/CINEMATICA.md (nodos wheel_fl/fr/rl/rr, disposición
    rectangular).
2026-08-23 Guarda el código fuente del visor 3D del robot
    cad-toreto/visor-3d/index.html: mismo contenido publicado como artifact,
    ya no depende solo de la carpeta temporal de la sesión. Three.js r128 +
    OrbitControls embebidos inline, sin CDN.
2026-08-23 Visor 3D: corrige el sentido de flexión del codo
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2026-08-23 Visor 3D: mano de 5 dedos articulados en vez de pinza de 3
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2026-08-23 Visor 3D: mano con nudillos giratorios (3 piezas por dedo, 2 el pulgar)
    Reemplaza el mecanismo de apertura por desplazamiento lateral (se quedaba
    fijo en 60%) por giro real de cada nudillo hacia dentro, como una mano.
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2026-08-23 Visor 3D: el pulgar cierra a la vez que los cuatro dedos, no al revés
2026-08-23 Visor 3D: pulgar perpendicular de verdad al plano de la palma (eje X, no Z)
2026-08-23 Cierra v0.1: forma del robot aprobada
    Issue #1 cerrado en GitHub. El punto de proporciones finales queda abierto
    a propósito -- no se cierra hasta fase 3 con componentes reales.
2026-08-25 Mueve las skills de Toreto a docs/.claude/skills
    Skills por subdirectorio: siguen activas pero el contenido vive dentro de
    docs/. La carpeta .claude de la raiz queda eliminada.
2026-08-25 Fusion 95cm: lamina maestra calibrada correctamente + trabajo exterior
    Guarda todo el trabajo de cad-toreto/toreto_fusion_95cm (add-ins de Fusion,
    lienzos, lamina maestra) y toreto_exterior_95cm (modulos OpenSCAD, STL,
    docs), antes sin versionar por decision deliberada (MIGRACION_95CM.md).
    El cambio real: tools/prepare_fusion_canvases.py escalaba la caja de
    recorte manual, no la silueta real -- las 4 vistas salian con dos escalas
    distintas (0.518 y 0.526 mm/px). Reescrito para calibrar cada vista contra
    su propia silueta, con validacion que falla si el resultado no cae entre
    Z=0 y Z=950mm. Las 4 vistas dan ahora 948.5-949.5mm de forma independiente.
    Fuente maestra verificada por hash, copi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
    [arms_exterior_95cm.scad, base_exterior_95cm.scad, chest_back_left.stl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]
2026-08-26 Fusion 95cm: herramienta reproducible para medir cotas Z, tabla sin fijar
    Mide las separaciones Z reales sobre el lienzo frontal calibrado
    (tools/measure_z_boundaries.py, regla de pixeles reproducible sobre la
    lamina maestra). El usuario decidio no fijar la tabla unica todavia: donde
    caen los cortes reales de tronco/cintura/pecho depende de donde queden
    bateria y mecanismos internos (fase 2), no solo de la silueta exterior.
    Los 10 add-ins de Fusion y los 5 modulos OpenSCAD siguen con sus valores
    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
2026-08-26 Fusion 95cm: corrige escala del add-in de referencias y cajas de silueta
    Trabajo de Codex (OpenAI Codex), en paralelo sobre la misma carpeta:
    - Toreto_Referencias_95cm.py -> 2.1.0: IMAGE_WIDTH_PX estaba en 1200,
    desfasado desde que prepare_fusion_canvases.py paso a lienzos de 2000px.
    Sin este fix, importar las referencias en Fusion escalaba mal.
    - Reaudita las 4 cajas de silueta (menos margen sobrante) y verifica la
    lamina maestra por SHA-256 (guardado en calibracion_95cm.json, que ahora
    usa ruta relativa en vez de una ruta absoluta de usuario).
    - measure_z_boundaries.py: corrige el mismo bug de escala que yo habia
    introducido (la regla de los zooms no se transformaba con display_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
2026-08-26 Actualiza README raiz y de cad-toreto: reflejan la estructura real
    Ambos describian solo maquetas OpenSCAD superadas (v2 y v0) y no
    mencionaban toreto_fusion_95cm/, toreto_exterior_95cm/ ni visor-3d/,
    que es donde vive todo el trabajo activo desde hace dias. Con dos IAs
    escribiendo en el mismo repo, un indice desactualizado es donde nacen
    inconsistencias como la de pecho 190 vs 228mm que ya se tuvo que depurar.
    Tambien afina la tabla de fases del README raiz: fase 3 esta en curso
    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
2026-08-26 Cierra decision IA local/nube: todo local, Jetson Orin Nano
    Bloqueaba el resto de fase 2. El usuario elige todo local en vez de nube
    o mixto: Jetson Orin Nano como unico ordenador de a bordo, sin Raspberry
    Pi adicional. Funciona sin conexion, mas caro que la alternativa nube,
    no usa Gemini/Google AI Pro para la IA embarcada.
    Queda anotado un pendiente para cuando se elijan motores/encoders: si el
    control de motores y la parada de emergencia por hardware necesitan un
    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
2026-08-26 Cierra LIDAR + camara RGB-D: RPLIDAR C1 + camara con IA integrada
    RPLIDAR C1 sobre A1M8 por alcance (12m vs 8m), soporte ROS2 oficial
    (rplidar_ros), estandar en tutoriales de Nav2.
    Camara: categoria con IA integrada (tipo OAK-D) en vez de RGB-D dedicada,
    para descargar computo del Jetson. Modelo exacto queda para la lista de
    compra.
    Se descartaron 3 camaras que el usuario ya tenia (Tapo C411, Tapo C230,
    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
2026-08-26 Referencias 95cm 2.3.0: segundo intento YZ + cifras de depuracion
    Intento 1 para YZ (sin intercambio de ejes) dio un resultado diminuto y
    mal ubicado en Fusion -- descartado, documentado en el docstring.
    Intento 2: reutilizar la disposicion numerica EXACTA que ya funciona en
    XZ (misma que tenia el codigo original antes de este fix, ya que XZ e YZ
    compartian formula). Sigue siendo hipotesis, no verificado.
    Anade _DEBUG_LINES: el mensaje final del add-in ahora imprime origen y
    vectores u/v en cm de cada lienzo, para poder comparar cifras exactas
    contra lo que Fusion mida en las esquinas del lienzo en vez de seguir
    ajustando a ojo sobre capturas de pantalla.
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2026-08-28 Ajusta la geometria de Fusion a los lienzos de referencia
    La lamina calibrada es la fuente maestra segun docs/DECISIONES.md, pero
    los add-ins llevaban cotas que no coinciden con ella. Medido con
    tools/measure_silhouette.py sobre los lienzos ya calibrados:
    Alturas (siguen sumando 950mm):
    alto_base 225 -> 200 mm
    alto_tronco 185 -> 190 mm
    alto_cintura 100 -> 150 mm
    alto_pecho 228 -> 190 mm
    alto_cuello 55 -> 60 mm
    alto_cabeza 157 -> 160 mm
    Anchos y fondos:
    diametro_base 400 -> 450 mm (el error mas grande)
    fondo_cabeza 175 -> 207 mm
    ancho_cabeza 285 -> 265 mm
    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
2026-08-31 Corrige redondeo de paneles del pecho
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2026-09-01 Flip head and arms to front and integrate finger roots
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2026-09-02 Correct arm flexion direction from four-view overlays
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2026-09-26 Checkpoint experimental hand repair and collision diagnostics
    Preserve isolated generator, geometry tests and Fusion reports. Main finger clearances improved; thumb collisions remain. Not a validated functional or manufacturing model.
2026-09-26 Mano de 4 motores: v8 todo limpio y pinza del boli lograda
    Decision de diseno (docs/DECISIONES.md): mano adaptativa de cuatro motores
    -- indice / corazon+anular+menique / flexion del pulgar / rotacion del
    pulgar (cardan) --, con tendones y muelles, para coger como una mano humana:
    boli con pulgar e indice, pelota pequena, vaso. Los motores concretos siguen
    pendientes (fase 2).
    Por que la mano no convergia: el ensayo cerraba los cinco dedos a la vez
    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
    [prueba_mano_4_motores_v7.json, prueba_mano_4_motores_v8.json]
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2026-09-27 Mano: pinza lateral del boli ensayada con sólidos (v10/v10b) y aceptada
    - Criba fuera de Fusion del apoyo plano del pulgar (study_thumb_pad.py y
    ESTUDIO_APOYO_PLANO.md), corregida para distinguir cara palmar, dorsal
    y lateral.
    - Escenario nuevo de pinza lateral: cardán completo e índice y flexión del
    pulgar cerrando 1:0,26, sin tocar geometría, topes ni relaciones.
    - Ensayo con sólidos que se detiene en el primer contacto, lo afina por
    bisección y clasifica la cara con la intersección directa.
    - v10: contacto al 78% sin choques previos, pero la cara quedó sin resolver
    (la penetración por diferencia es ruido en contactos rozantes).
    - v10b: manda la intersección directa y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
    [prueba_mano_4_motores_v10.json, prueba_mano_4_motores_v10b.json]
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2026-09-27 Hombro sin tocar el pecho: taladro prolongado hasta pasar el conector (v13b)
    - Interferencia en el montaje: la carcasa del brazo rozaba el conector del
    hombro del pecho (1806,8 mm3 en cada brazo): el taladro empezaba en X
    167,4 y el conector en 166, y la carcasa baja inclinada unos 15°.
    - El taladro va ahora de X 164,0 a 224,6, coaxial y con R37,3 > R36,5: el
    conector queda entero dentro del hueco y no puede tocar la carcasa. Una
    prueba lo comprueba y falla con el taladro de la v13.
    - En el montaje (…_backup): brazo reemplazado por v13b, mano izquierda
    rearticulada y la fila del conector desaparecida en los dos brazos.
    - Documento de relevo: el montaje bueno es el …_backup.
2026-09-28 Hombro unido al pecho como en la lámina (pecho 2.6.0 y brazo v13c)
    - El usuario vio un hueco de ~40 mm entre pecho y brazo: el conector del
    pecho 2.5.0 solo existía dentro del brazo (X 166-196,5); la interferencia
    salía limpia justo porque no se tocaban.
    - Pecho 2.6.0: pieza de hombro medida sobre la lámina frontal, coaxial con
    el eje del hombro: disco R47 (X 124-130, entra 2 mm en el pecho), disco
    R39, cuello R29, disco R39 (hasta 157) y el eje R36,5 que entra en el
    brazo (157-196,5).
    - Brazo v13c: taladro desde X 155. La carcasa del brazo no baja de X 159,3,
    así que los discos no la tocan y el eje cabe entero en el taladro.
    - Pruebas: discos a >= 2 mm del brazo, pieza cont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
2026-09-29 Brazo v14: hombro en cápsula redonda con disco negro, colores blanco/negro y modo de interferencias (0 choques)
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2026-10-02 Pecho 3.0.0: 327 mm con la ROG Ally X a la vista, rejillas de aire y aro fino del hombro; modo comprobar (alturas + interferencias)
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
